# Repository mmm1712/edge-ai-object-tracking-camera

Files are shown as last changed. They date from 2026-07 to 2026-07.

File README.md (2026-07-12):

# Local Edge AI Object-Tracking Camera

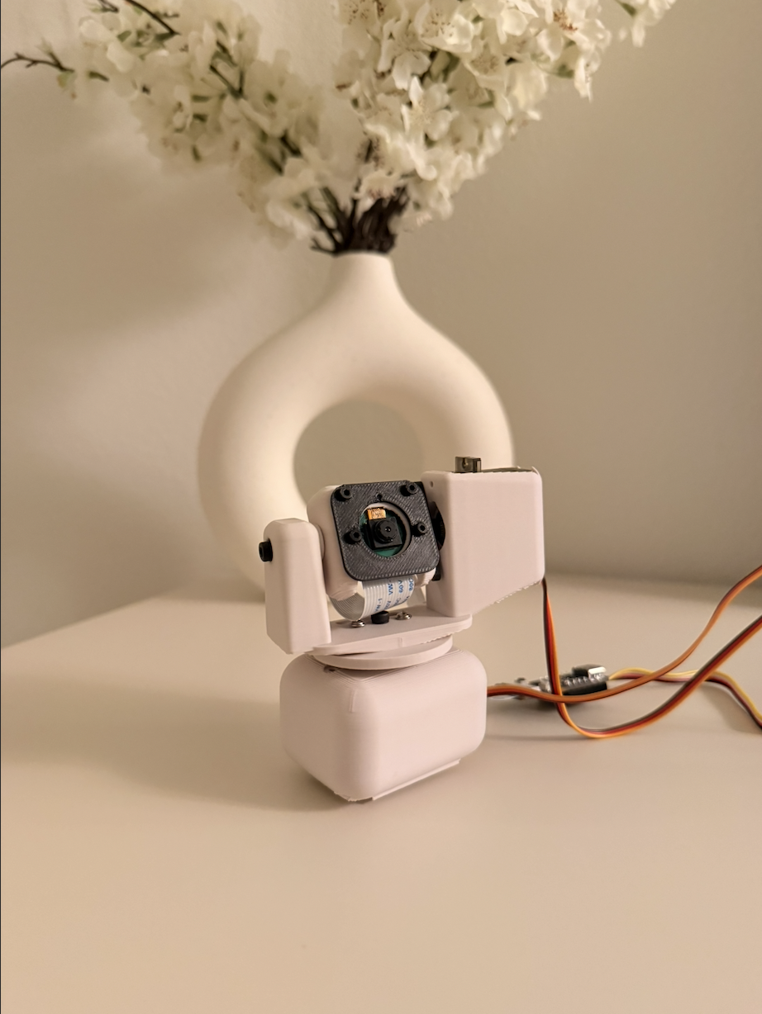
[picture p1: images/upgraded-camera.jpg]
Upgraded object-tracking camera


## Why I Rebuilt It

My first object-tracking camera used an ESP32-CAM to stream video to my laptop. A YOLO model running on the laptop detected the object, and the laptop sent movement commands to another ESP32 controlling the servos.

It worked, but the camera could not track anything without my laptop.

In this upgraded version, object detection runs locally on Grove Vision AI V2. The detected object position is sent to a XIAO ESP32-S3, which controls the pan and tilt servos.

I also redesigned the 3D-printed camera body to fit the new hardware.

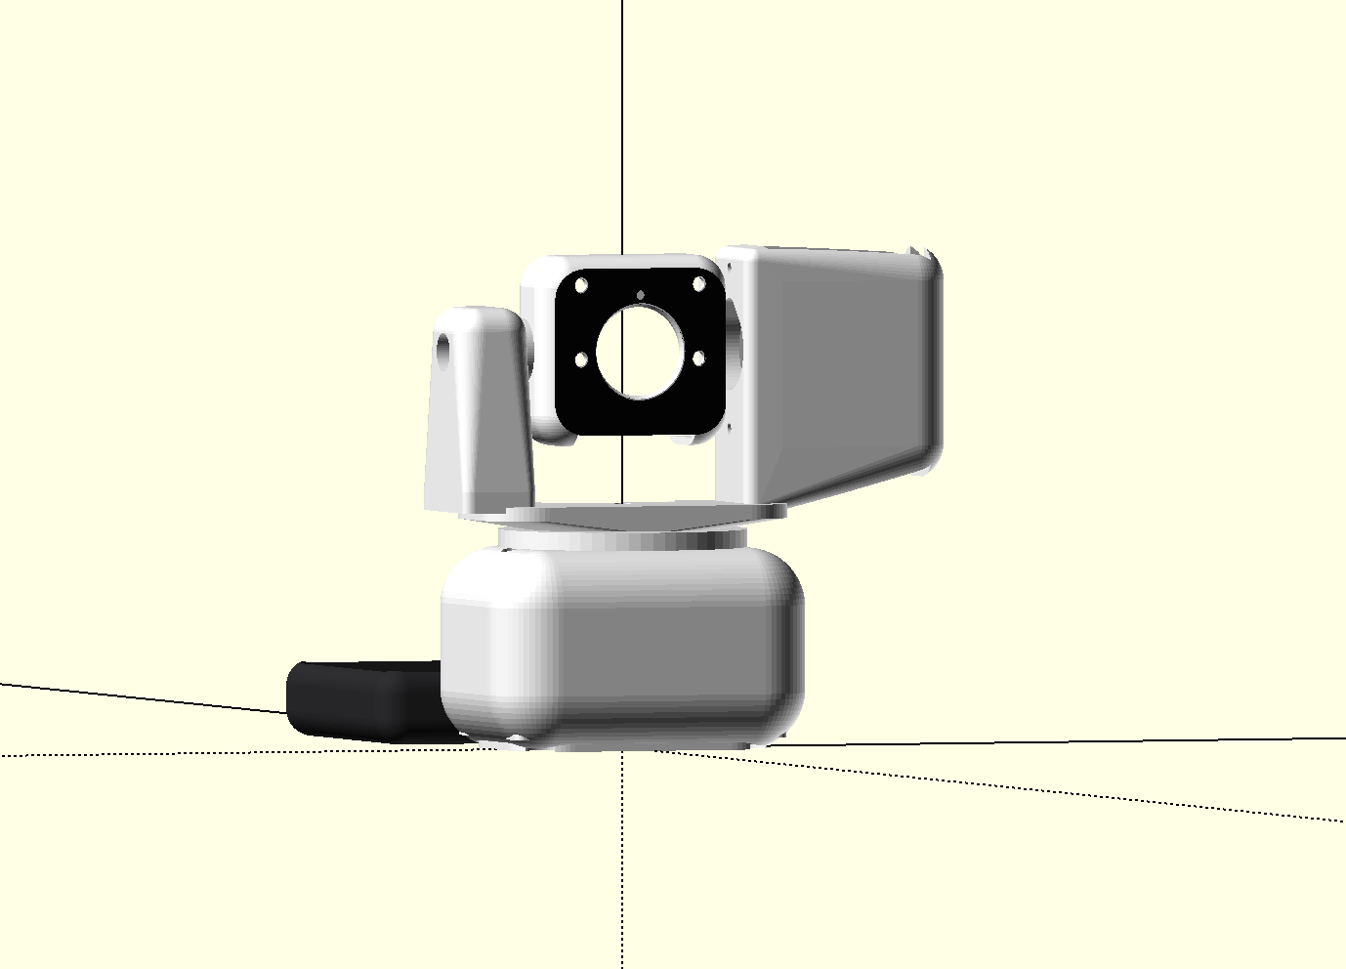
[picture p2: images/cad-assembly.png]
OpenSCAD assembly


## How It Works

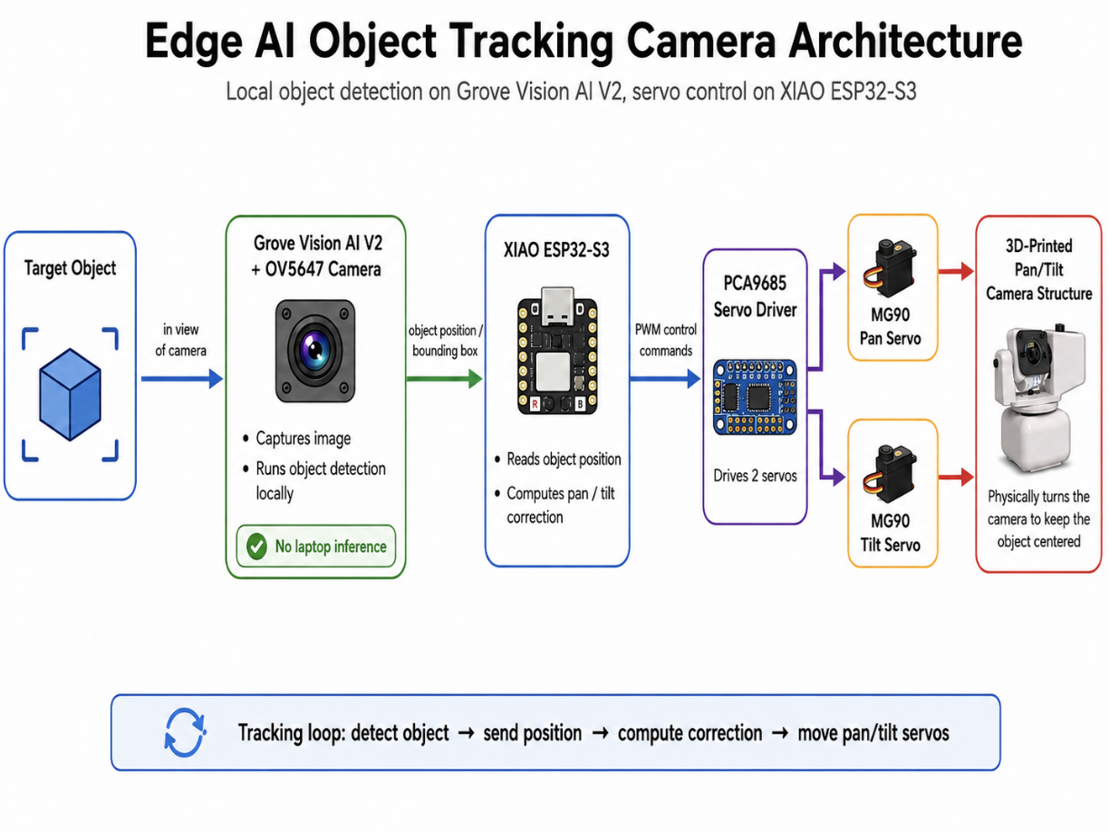
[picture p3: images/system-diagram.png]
Object-tracking system diagram


1. Grove Vision AI V2 detects the object.
2. It sends the object's position to the XIAO.
3. The XIAO compares that position with the center of the camera frame.
4. If the object is off-center, the XIAO moves the pan and tilt servos.
5. The camera turns toward the object.

Object detection and servo control now run locally on the device.

## Demo

Camera following an object

The upgraded prototype can now detect an object, decide where to move, and physically follow it without relying on a laptop.

## Hardware

- Grove Vision AI V2 Kit
- XIAO ESP32-S3
- OV5647-62 FOV camera module
- 2 × MG90S metal gear micro servos
- PCA9685 servo driver
- External 5 V servo power supply
- Custom 3D-printed pan/tilt structure
- Jumper wires and mounting hardware

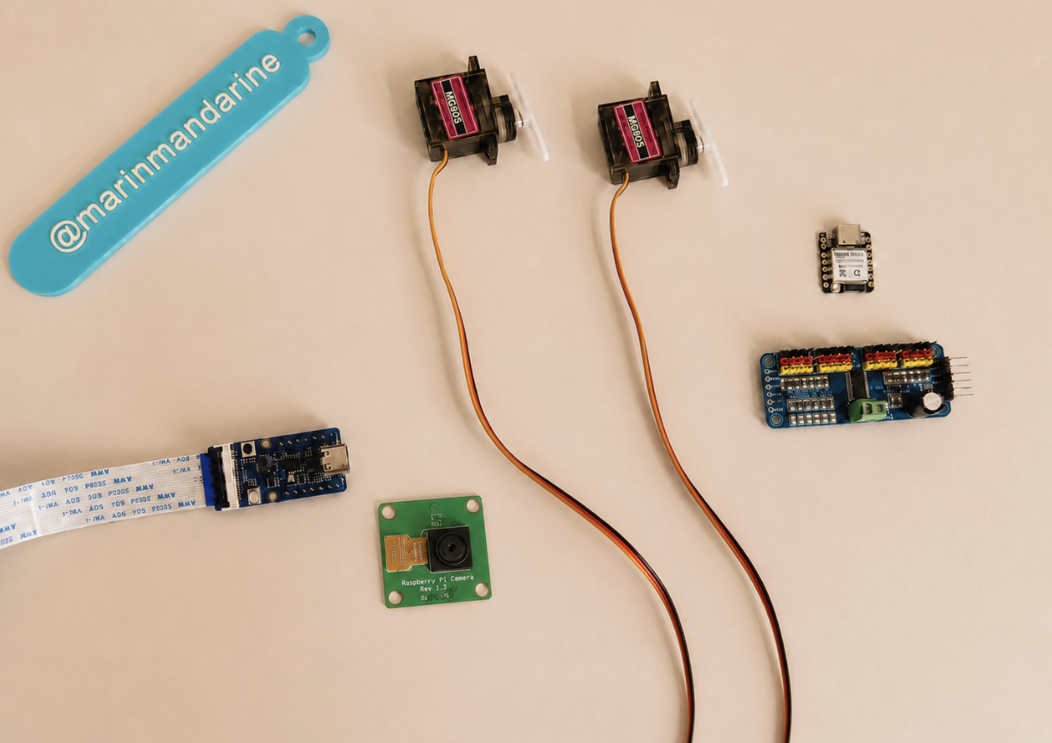
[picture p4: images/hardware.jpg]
Main hardware


## Servo Control

The XIAO checks how far the object is from the center of the frame:

```cpp
errorX = objectCenterX - frameCenterX;
errorY = objectCenterY - frameCenterY;
```

The error is converted into a target servo speed:

```cpp
panSpeed  = clamp(KpPan * errorX, -maxPanSpeed, maxPanSpeed);
tiltSpeed = clamp(KpTilt * errorY, -maxTiltSpeed, maxTiltSpeed);
```

If the object is far from the center, the camera moves faster. If it is only slightly off-center, it moves more slowly.

A dead zone prevents tiny movements when the object is already close to the center. Acceleration limits make the speed change gradually instead of jumping instantly.

Accurate detection alone is not enough. Smooth and stable servo control is also important for reliable tracking.

## Wiring

See [`docs/wiring.md`](docs/wiring.md).

The servos use an external 5 V power supply. The external power ground and XIAO ground must be connected together.

## Software

### Required Arduino Libraries

- Seeed Arduino SSCMA
- Adafruit PWM Servo Driver Library

### Uploading the Firmware

1. Install the required libraries in Arduino IDE.
2. Open:
   `firmware/grove_vision_ai_object_tracker/grove_vision_ai_object_tracker.ino`
3. Select the XIAO ESP32-S3 board and the correct port.
4. Upload the sketch.
5. Open Serial Monitor at `115200` baud.
6. A successful start should print:

```text
AI BEGIN OK
```

### Tracking Settings

The most important values are grouped near the beginning of the sketch:

- Servo center positions
- Mechanical movement limits
- Servo directions
- Proportional gains
- Maximum speed
- Acceleration
- Dead-zone sizes
- Detection smoothing

These values may need small adjustments for a different pan/tilt structure.

## Original Version vs. Upgraded Version

### Original Version

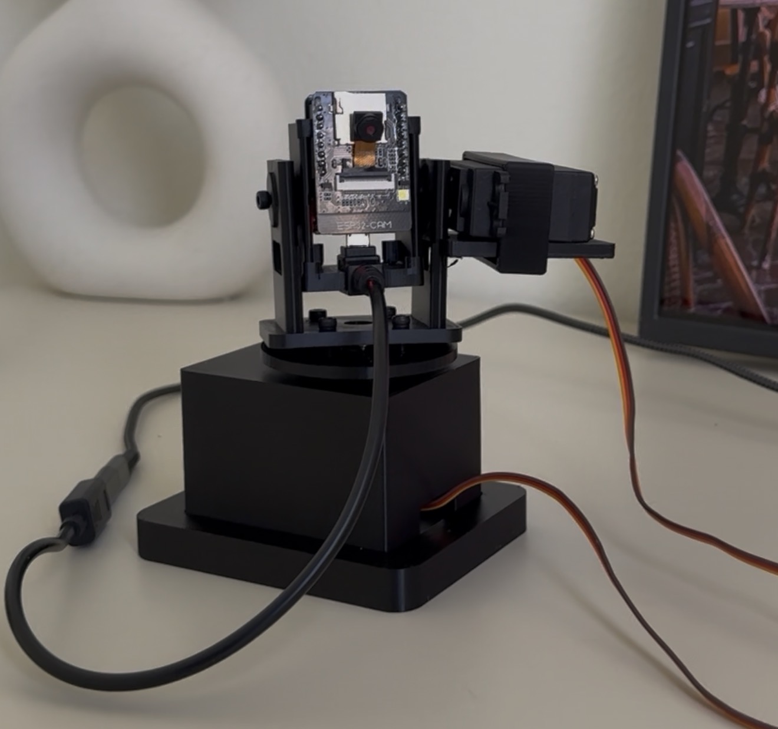
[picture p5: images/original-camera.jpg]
Original camera


The original version streamed video to my laptop, where a YOLO model detected the object.

### Upgraded Version

The upgraded version runs object detection locally on Grove Vision AI V2.

| Feature | Original Version | Upgraded Version |
| --- | --- | --- |
| Camera system | ESP32-CAM | Grove Vision AI V2 + OV5647 camera |
| AI inference | Laptop | Grove Vision AI V2 |
| Servo control | Second ESP32 | XIAO ESP32-S3 + PCA9685 |
| Servos | MG995/MG996-style servos | MG90S servos |
| Tracking loop | Laptop YOLO + serial commands | Local detection + servo control |
| Portability | Limited | More compact |
| Main limitation | Required laptop inference | Still needs a cleaner enclosure and power system |

The biggest upgrade is not only the hardware. It is the architecture. Moving object detection onto the embedded vision module brings the project much closer to a standalone edge AI camera.

## Project Structure

```text
edge-ai-object-tracking-camera/
├── firmware/
│   └── grove_vision_ai_object_tracker/
│       └── grove_vision_ai_object_tracker.ino
├── docs/
│   └── wiring.md
├── images/
│   ├── cad-assembly.png
│   ├── hardware.jpg
│   ├── original-camera.jpg
│   ├── system-diagram.png
│   ├── tracking-demo.gif
│   ├── upgraded-camera.jpg
│   └── README.md
├── cad/
│   ├── source/
│   │   └── object_tracking_camera.scad
│   ├── stl/
│   │   ├── base.stl
│   │   ├── base_cover.stl
│   │   ├── yoke.stl
│   │   ├── camera_head.stl
│   │   └── faceplate_insert.stl
│   └── README.md
├── .gitignore
├── LICENSE
└── README.md
```

## What I Want to Improve Next

- Cleaner wiring
- A better electronics enclosure
- Battery power and power management
- Smoother servo movement
- Better mechanical balance
- More latency and response-time testing
- A larger and more varied training dataset

One future idea is to turn this into a small nature or wildlife monitoring camera. That would require a stronger enclosure, reliable power, and environmental protection.

## Current Status

This is still a prototype, but the main local edge AI tracking loop is working.

The camera can now:

- Detect the object locally
- Send its position to the XIAO
- Move the pan and tilt servos
- Follow the object without a laptop

## License

This project is available under the MIT License.

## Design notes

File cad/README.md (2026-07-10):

# CAD Files

This folder contains the 3D-printable parts and the OpenSCAD source file for the custom pan/tilt camera structure.

## Folder Structure

```text
cad/
├── source/
│   └── object_tracking_camera.scad
├── stl/
│   ├── base.stl
│   ├── base_cover.stl
│   ├── yoke.stl
│   ├── camera_head.stl
│   └── faceplate_insert.stl
└── renders/

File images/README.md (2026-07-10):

# Project Images

This folder contains the main photos, diagrams, and demo files used in the project README.

## Files

- `tracking-demo.gif` - demo of the camera following the detected object
- `original-camera.jpg` — the first ESP32-CAM version that depended on a laptop
- `upgraded-camera.jpg` — the upgraded camera using Grove Vision AI V2 and XIAO ESP32-S3
- `hardware.jpg` — the main hardware used to build the upgraded version
- `system-diagram.png` — diagram showing how object detection and servo control work
- `cad-assembly.png` — OpenSCAD render of the custom pan/tilt camera structure

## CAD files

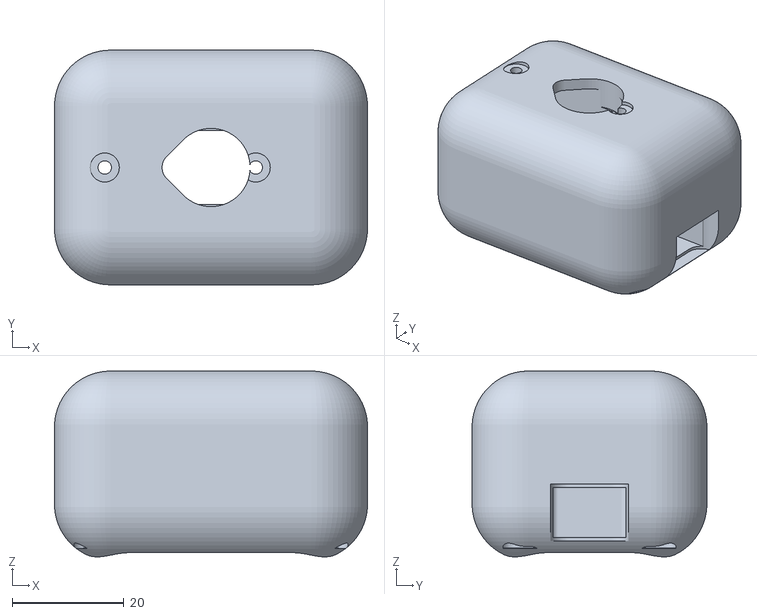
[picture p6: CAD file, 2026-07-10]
cad/stl/base.stl
56.0 x 42.0 x 33.2

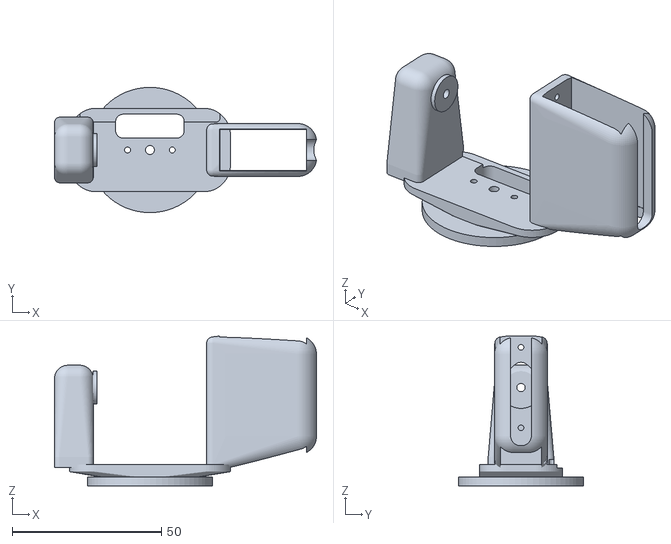
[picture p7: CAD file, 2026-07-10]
cad/stl/yoke.stl
87.9 x 42.0 x 50.3

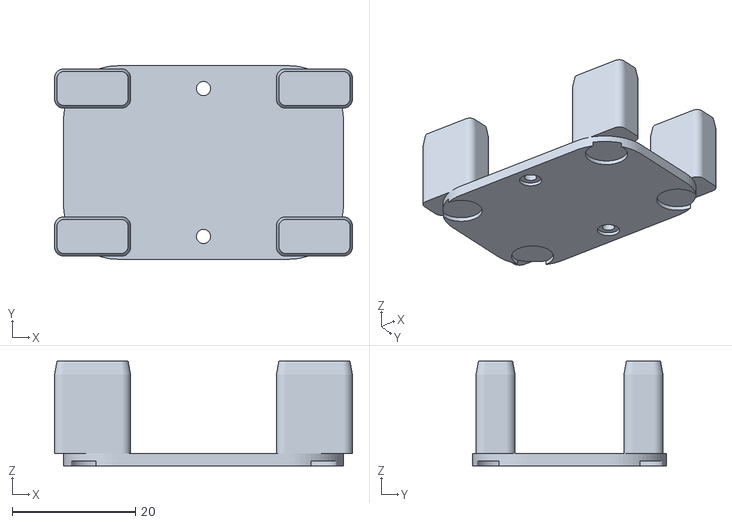
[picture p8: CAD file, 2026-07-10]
cad/stl/base_cover.stl
48.4 x 31.4 x 17.0

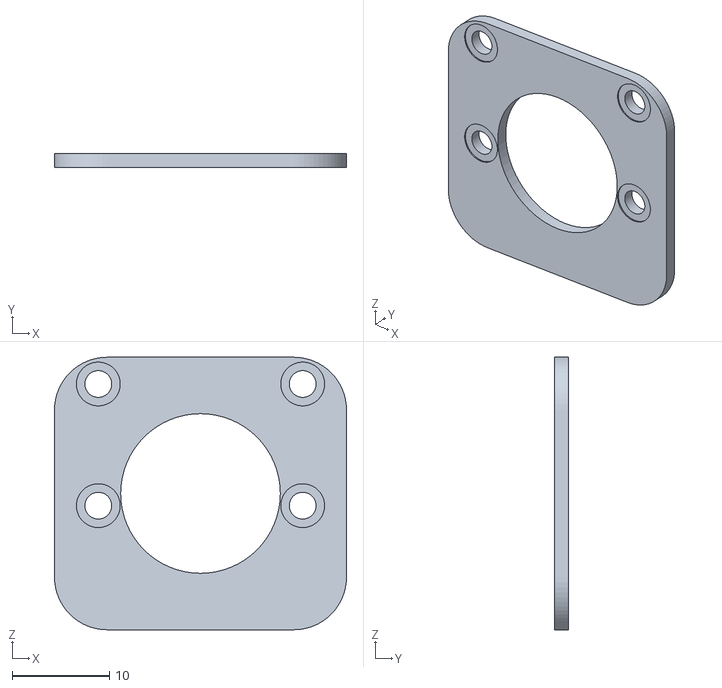
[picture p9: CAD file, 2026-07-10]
cad/stl/faceplate_insert.stl
30.0 x 1.40 x 28.0

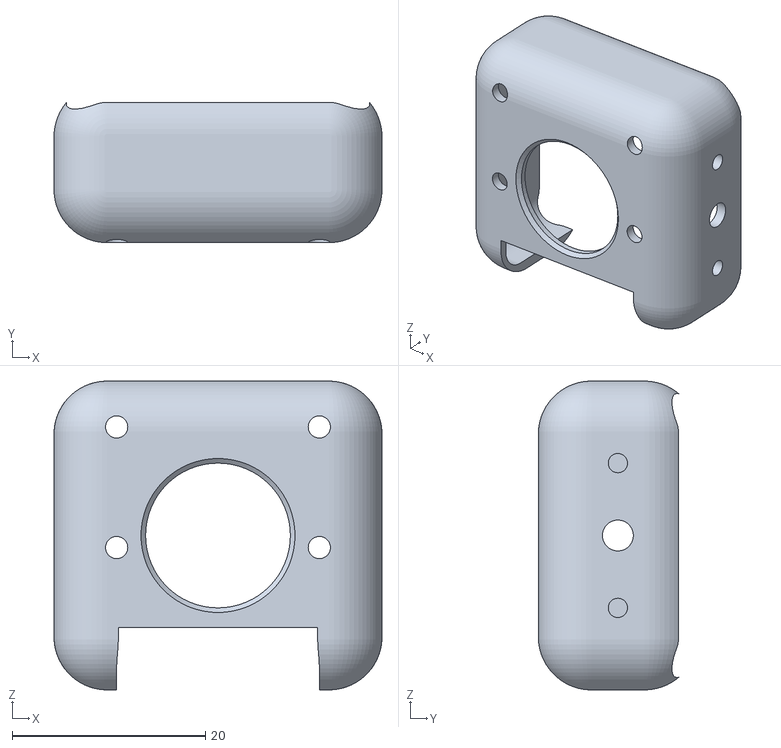
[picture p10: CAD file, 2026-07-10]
cad/stl/camera_head.stl
34.0 x 14.5 x 32.0

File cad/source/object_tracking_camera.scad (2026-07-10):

$fn = 64;
eps = 0.01;

show_part = "assembly";
/*
  Options:
  "assembly"
  "base"
  "base_cover"
  "yoke"
  "camera_head"
  "faceplate_insert"
*/

sv_body_w = 12.2;
sv_body_d = 28.5;
sv_tab_l = 32.5;
sv_screw_d = 2.4;
sv_screw_sp = 27.0;
sv_shaft_off = 5.5;
sv_boss_d = 14.0;
sv_boss_nose = 5.5;

cam_screw_sp_x = 21.0;
cam_screw_sp_z = 12.5;
cam_hole_z_off = 5.0;
cam_screw_d = 2.3;
lens_d = 15.0;
fpc_w = 21.0;

base_w = 56;
base_d = 42;
base_h = 33.8;
deck_t = 2.4;
yoke_axis_z = 33;
arm_in_x = 19;
head_w = 34;
head_d = 16.5;
head_h = 32;

side_pod_h = 40.0;
side_pod_y = 17.8;
side_pod_r = 6.4;
side_pod_zc = 30.5;

base_cover_tab_clear = 0.65;
base_cover_tab_h = 15.0;
base_cover_tab_lead_h = 2.2;
base_cover_tab_x = 13.0 - base_cover_tab_clear;
base_cover_tab_y = 7.0 - base_cover_tab_clear;
base_cover_tab_lead_x = base_cover_tab_x - 0.8;
base_cover_tab_lead_y = base_cover_tab_y - 0.8;

wall_t = 13;
module soft_box(size=[10,10,10], r=3) {
    x=size[0]; y=size[1]; z=size[2];
    hull()
    for (xx=[-x/2+r, x/2-r])
    for (yy=[-y/2+r, y/2-r])
    for (zz=[-z/2+r, z/2-r])
        translate([xx,yy,zz]) sphere(r=r);
}

module rounded_box(size=[10,10,10], r=2) {
    x=size[0]; y=size[1]; z=size[2];
    hull()
    for (xx=[-x/2+r, x/2-r])
    for (yy=[-y/2+r, y/2-r])
        translate([xx,yy,0]) cylinder(h=z, r=r, center=true);
}


module rounded_plate_xz(w=20, z=20, t=1.0, r=4) {
    hull()
    for (xx=[-w/2+r, w/2-r])
    for (zz=[-z/2+r, z/2-r])
        translate([xx, 0, zz])
            rotate([90,0,0]) cylinder(r=r, h=t, center=true);
}

module hole_x(d=3, h=20) { rotate([0,90,0]) cylinder(d=d, h=h, center=true); }

module hole_y(d=3, h=20) { rotate([90,0,0]) cylinder(d=d, h=h, center=true); }

module hole_z(d=3, h=20) { cylinder(d=d, h=h, center=true); }

module boss_clear_z(d=14, nose_d=5.5, nose_off=-5.5, h=12) {
    hull() {
        hole_z(d=d, h=h);
        translate([nose_off,0,0]) hole_z(d=nose_d, h=h);
    }
}

module base() {
    difference() {
        translate([0,0,base_h/2])
            soft_box([base_w, base_d, base_h], r=10);

        translate([-sv_shaft_off, 0, (base_h - deck_t)/2 - 0.1])
            rounded_box([sv_tab_l + 1.0, sv_body_w + 1.0, base_h - deck_t + 0.2], r=1.0);

        translate([0,0,base_h - deck_t/2])
            boss_clear_z(d=sv_boss_d, nose_d=sv_boss_nose, nose_off=-6.0, h=deck_t + 8);

        for (xx = [-sv_screw_sp/2, sv_screw_sp/2]) {
            translate([-sv_shaft_off + xx, 0, base_h/2])
                hole_z(d=sv_screw_d, h=base_h + 4);
            translate([-sv_shaft_off + xx, 0, base_h - 0.35])
                hole_z(d=5.2, h=0.8);
        }

        translate([0,0,0])
            rounded_box([46, 32, 4.4], r=9);

        for (yy = [-12, 12])
            translate([0, yy, 5])
                hole_z(d=1.7, h=10);

        for (xx = [-18, 18]) for (yy = [-12, 12])
            translate([xx, yy, 15.1])
                rounded_box([13, 7, 26], r=2);

        translate([base_w/4 + 3.0, 0, 8.5])
            rounded_box([base_w/2 + 12, 13.0, 9.0], r=2.7);

        translate([base_w/2 - 1.2, 0, 8.5])
            rounded_box([8.0, 14.0, 10.2], r=3.2);
    }
}

module base_cover_locator_tab() {

    hull() {
        translate([0,0,(base_cover_tab_h - base_cover_tab_lead_h)/2])
            rounded_box([base_cover_tab_x,
                         base_cover_tab_y,
                         base_cover_tab_h - base_cover_tab_lead_h], r=1.45);
        translate([0,0,base_cover_tab_h - base_cover_tab_lead_h/2])
            rounded_box([base_cover_tab_lead_x,
                         base_cover_tab_lead_y,
                         base_cover_tab_lead_h], r=1.2);
    }
}

module base_cover() {
    difference() {
        union() {

            translate([0,0,1.0])
                rounded_box([45.4, 31.4, 2.0], r=8.7);

            for (xx = [-18, 18]) for (yy = [-12, 12])
                translate([xx, yy, 2.0])
                    base_cover_locator_tab();
        }

        for (yy = [-12, 12]) {
            translate([0, yy, 1.0]) hole_z(d=2.3, h=6 + base_cover_tab_h);
            translate([0, yy, 0.3]) hole_z(d=4.2, h=0.7);
        }

        for (xx = [-17.5, 17.5]) for (yy = [-11, 11])
            translate([xx, yy, 0])
                hole_z(d=8, h=1.6);
    }
}

module left_minimal_arm(t=wall_t) {
    difference() {
        union() {
            hull() {

                translate([-arm_in_x - t/2, 0, 8.0])
                    rounded_box([t, 22.0, 3.6], r=1.8);

                translate([-arm_in_x - t/2, 0, yoke_axis_z])
                    soft_box([t, 17.5, 15], r=4.5);
            }

            translate([-arm_in_x + 0.6, 0, yoke_axis_z])
                rotate([0,90,0]) cylinder(d=11, h=1.4, center=true);
        }

        translate([-arm_in_x - t + 2.0, 0, yoke_axis_z])
            hole_x(d=6.5, h=4.6);

        translate([-arm_in_x - t/2 - 0.6, 0, yoke_axis_z])
            hole_x(d=3.4, h=t - 8.0);

        translate([-arm_in_x - 1.6, 0, yoke_axis_z])
            hole_x(d=2.8, h=6.6);
    }
}

module yoke() {
    axis = yoke_axis_z;
    plate_x0 = arm_in_x;
    plate_t  = 4.4;
    plate_x1 = plate_x0 + plate_t;
    body_x0  = plate_x1 + 0.25;
    cowl_x1  = body_x0 + sv_body_d + 2.2;
    difference() {
        union() {

            cylinder(d=42, h=3);

            hull() {
                translate([0,0,2.6]) cylinder(d=28, h=0.6);
                translate([0,0,5.4]) rounded_box([54, 28, 1.2], r=9);
            }

            translate([0,0,6.0]) rounded_box([54, 28, 2.4], r=9);

            difference() {
                hull() {
                    translate([(plate_x0+plate_x1)/2, 0, (axis + 17 + 5)/2])
                        soft_box([plate_t, 17.6, axis + 17 - 5], r=2.2);
                    translate([(plate_x0 + cowl_x1 + 1.6)/2, 0, side_pod_zc])
                        soft_box([cowl_x1 - plate_x0 + 1.6, side_pod_y, side_pod_h], r=side_pod_r);
                }

                translate([(plate_x1 + cowl_x1 - 2.0)/2 + 0.05, 0, 36.25])
                    cube([cowl_x1 - 2.0 - plate_x1 + 0.3, sv_body_w + 1.8, 42.0], center=true);

                translate([(body_x0 + cowl_x1 - 2.0)/2, 0, 10])
                    cube([cowl_x1 - 2.0 - body_x0 + 0.2, sv_body_w + 1.6, 13.5], center=true);

                translate([cowl_x1, 0, 36.0])
                    rotate([0,90,0])
                        rounded_box([45.0, 7.0, 10.0], r=3.4);
            }

            left_minimal_arm();
        }

        translate([0,0,1.3 - eps]) {
            cylinder(d=9.2, h=2.7, center=true);
            rounded_box([36.5, 7.4, 2.7], r=2);
        }

        hole_z(d=3.0, h=18);
        for (xx = [-7.5, 7.5])
            translate([xx,0,0]) hole_z(d=2.0, h=16);

        translate([0, 8.0, 4]) rounded_box([23, 8.0, 12], r=2.5);

        translate([0, 12.3, 7.4]) rounded_box([47, 5.8, 2.8], r=1.2);

        translate([(plate_x0+plate_x1)/2, 0, axis])
            hull() {
                hole_x(d=sv_boss_d, h=plate_t + 10);
                translate([0,0,5.5]) hole_x(d=6.0, h=plate_t + 10);
            }

        for (zz = [-sv_screw_sp/2, sv_screw_sp/2])
            translate([(plate_x0+plate_x1)/2, 0, axis + zz])
                hole_x(d=1.9, h=plate_t + 8);

        for (xx = [26, 30])
            translate([xx, 7.5, 11])
                rounded_box([1.8, 6, 7], r=0.8);
    }
}

module camera_head() {
    difference() {

        soft_box([head_w, head_d, head_h], r=5.5);

        translate([0, 1.3, 0])
            soft_box([head_w - 2.6, head_d + 0.2, head_h - 2.6], r=3.0);

        translate([0, 5.6, 0])
            rounded_box([27.5, 12.0, 26.5], r=4);

        translate([0, -head_d/2, 0]) hole_y(d=lens_d, h=head_d + 6);
        translate([0, -head_d/2 - 0.4, 0])
            rotate([90,0,0])
                cylinder(d1=lens_d, d2=lens_d + 3.5, h=1.8, center=true);

        for (x = [-cam_screw_sp_x/2, cam_screw_sp_x/2])
        for (z = [-cam_screw_sp_z/2, cam_screw_sp_z/2])
            translate([x, -head_d/2 + 0.7, z + cam_hole_z_off])
                hole_y(d=cam_screw_d, h=4);

        translate([0, 1, -head_h/2 + 3.2])
            rounded_box([fpc_w, head_d + 6, 6.5], r=3);
        translate([0, head_d/2 - 1, -9])
            rotate([0,90,0])
                rounded_box([13, 8, fpc_w], r=4);

        translate([-head_w/2, 0, 0]) hole_x(d=4.2, h=12);

        translate([head_w/2, 0, 0]) {
            hole_x(d=3.2, h=12);
            for (zz = [-7.5, 7.5])
                translate([0, 0, zz]) hole_x(d=2.0, h=12);
        }
    }
}


module camera_faceplate_insert() {
    fp_y = -head_d/2 - 0.68;
    fp_t = 1.4;
    fp_w = head_w - 4.0;
    fp_z = head_h - 4.0;
    fp_r = 5.4;
    faceplate_screw_access_d = cam_screw_d + 0.45;
    faceplate_screw_bezel_d = 4.5;

    difference() {
        translate([0, fp_y, 0])
            rounded_plate_xz(w=fp_w, z=fp_z, t=fp_t, r=fp_r);

        translate([0, fp_y, 0])
            hole_y(d=lens_d + 1.4, h=fp_t + 3);
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

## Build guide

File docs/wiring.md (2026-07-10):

# Wiring

The project uses two separate I2C buses on the XIAO ESP32-S3.

## Grove Vision AI V2

| Signal | XIAO ESP32-S3 |
| --- | --- |
| SDA | GPIO 5 |
| SCL | GPIO 6 |
| GND | GND |
| Power | Connect according to the module requirements |

## PCA9685 Servo Driver

| Signal | XIAO ESP32-S3 |
| --- | --- |
| SDA | GPIO 9 |
| SCL | GPIO 7 |
| GND | GND |
| Logic power | Connect according to the PCA9685 board requirements |

## Servos

| Servo | PCA9685 Channel |
| --- | --- |
| Pan | 0 |
| Tilt | 1 |

The servos are powered from an external 5 V supply.

**Important:** Connect the external power supply ground to the XIAO ground so all parts of the system share the same reference.

Do not power both servos from the XIAO 3.3 V pin.

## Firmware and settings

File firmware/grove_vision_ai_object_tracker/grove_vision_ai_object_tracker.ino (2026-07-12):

/*
  Local Edge AI Object-Tracking Camera

  Hardware:
  - Grove Vision AI V2
  - Seeed Studio XIAO ESP32-S3
  - PCA9685 servo driver
  - 2 x MG90S servos
  - External 5 V servo power supply

  Libraries:
  - Seeed Arduino SSCMA
  - Adafruit PWM Servo Driver Library

  Wiring used in this project:
  Grove Vision AI V2:
    SDA -> XIAO D4 / GPIO 5
    SCL -> XIAO D5 / GPIO 6

  PCA9685:
    SDA -> XIAO GPIO 9
    SCL -> XIAO GPIO 7

  Important:
  Power the servos from an external 5 V supply and connect
  the external supply ground to the XIAO ground.
*/

#include <Arduino.h>
#include <Wire.h>
#include <Adafruit_PWMServoDriver.h>
#include <Seeed_Arduino_SSCMA.h>

#define AI_SDA 5
#define AI_SCL 6
#define PCA_SDA 9
#define PCA_SCL 7
#define PCA9685_ADDR 0x40

TwoWire AIWire = TwoWire(0);
TwoWire ServoWire = TwoWire(1);

SSCMA AI;
Adafruit_PWMServoDriver pwm(PCA9685_ADDR, ServoWire);

constexpr float FRAME_WIDTH = 240.0f;
constexpr float FRAME_HEIGHT = 240.0f;
constexpr float FRAME_CENTER_X = FRAME_WIDTH / 2.0f;
constexpr float FRAME_CENTER_Y = FRAME_HEIGHT / 2.0f;

constexpr int PAN_CHANNEL = 0;
constexpr int TILT_CHANNEL = 1;
constexpr int SERVO_MIN_PULSE = 110;
constexpr int SERVO_MAX_PULSE = 500;
constexpr int SERVO_TICK_MS = 20;

constexpr int MIN_DETECTION_SCORE = 50;

constexpr unsigned long TARGET_STALE_MS = 550;

constexpr float FILTER_ALPHA_X = 0.62f;

constexpr float FILTER_ALPHA_Y = 0.30f;
constexpr float BASE_MAX_Y_JUMP_PX = 30.0f;
constexpr float BOX_HEIGHT_JUMP_SCALE = 0.45f;
constexpr int STRONG_Y_JUMP_SCORE = 82;
constexpr int Y_JUMP_CONFIRM_FRAMES = 2;
constexpr float Y_JUMP_CONFIRM_TOLERANCE_PX = 16.0f;

constexpr float Y_LOCK_PAN_ERROR_PX = 22.0f;
constexpr float Y_LOCK_MAX_Y_ERROR_PX = 18.0f;
constexpr float TILT_AIM_OFFSET_Y_PX = 0.0f;

constexpr uint16_t AI_I2C_ADDRESS = 0x62;
constexpr uint32_t AI_I2C_WAIT_MS = 1;
constexpr uint32_t AI_I2C_CLOCK_HZ = 400000;

constexpr int INVOKE_FAILURE_BACKOFF_MS = 20;

struct AxisController {
  int channel;
  float minAngle;
  float centerAngle;
  float maxAngle;
  int direction;
  float deadzonePx;
  float kp;
  float maxVelocityDps;
  float minVelocityDps;
  float accelerationDps2;
  float currentAngle;
  float currentVelocityDps;
  int lastPulse;
};

struct TargetTracker {
  float filteredX;
  float filteredY;

  float errorX;
  float errorY;

  float pendingY;
  int pendingYFrames;

  int lastRawY;
  int lastScore;
  bool lastYRejected;

  bool filterReady;
  bool targetVisible;
  unsigned long lastSeenMs;
};

AxisController panAxis = {
  PAN_CHANNEL,
  35.0f,
  90.0f,
  145.0f,
  -1,
  8.0f,
  1.65f,
  145.0f,
  3.5f,
  700.0f,
  90.0f,
  0.0f,
  -1
};

AxisController tiltAxis = {
  TILT_CHANNEL,
  95.0f,
  125.0f,
  140.0f,
  -1,
  14.0f,    
  1.85f,   
  125.0f,   
  4.0f,
  650.0f,  
  125.0f,
  0.0f,
  -1
};

TargetTracker tracker = {
  FRAME_CENTER_X,
  FRAME_CENTER_Y,
  0.0f,
  0.0f,
  FRAME_CENTER_Y,
  0,
  0,
  0,
  false,
  false,
  false,
  0
};

SemaphoreHandle_t stateMutex;

bool aiOK = false;
bool trackingEnabled = false;

portMUX_TYPE statsMux = portMUX_INITIALIZER_UNLOCKED;

uint32_t totalInvokeOK = 0;
uint32_t totalInvokeFail = 0;

uint32_t windowInvokeOK = 0;
uint32_t windowInvokeFail = 0;
uint32_t windowDetectionFrames = 0;

uint64_t windowInvokeTimeUs = 0;
uint32_t lastInvokeUs = 0;

int lastPreprocessMs = 0;
int lastInferenceMs = 0;
int lastPostprocessMs = 0;

unsigned long lastTimingPrintMs = 0;

float clampFloat(float value, float minimum, float maximum) {
  if (value < minimum) return minimum;
  if (value > maximum) return maximum;
  return value;
}

float absFloat(float value) {
  return value < 0.0f ? -value : value;
}

float signFloat(float value) {
  if (value > 0.0f) return 1.0f;
  if (value < 0.0f) return -1.0f;
  return 0.0f;
}

float moveToward(float current, float target, float maxChange) {
  float difference = target - current;
  if (absFloat(difference) <= maxChange) return target;
  return current + signFloat(difference) * maxChange;
}

float easeOutCubic(float value) {
  value = clampFloat(value, 0.0f, 1.0f);
  float remaining = 1.0f - value;
  return 1.0f - remaining * remaining * remaining;
}

int angleToPulse(float angle) {
  angle = clampFloat(angle, 0.0f, 180.0f);
  float normalized = angle / 180.0f;
  return static_cast<int>(
    SERVO_MIN_PULSE +
    normalized * (SERVO_MAX_PULSE - SERVO_MIN_PULSE) +
    0.5f
  );
}

void writeAxis(AxisController &axis) {
  axis.currentAngle = clampFloat(
    axis.currentAngle,
    axis.minAngle,
    axis.maxAngle
  );

  int pulse = angleToPulse(axis.currentAngle);
  if (pulse == axis.lastPulse) return;

  axis.lastPulse = pulse;
  pwm.setPWM(axis.channel, 0, pulse);
}

void writeServos() {
  writeAxis(panAxis);
  writeAxis(tiltAxis);
}

float calculateTargetVelocity(float error, const AxisController &axis) {
  float magnitude = absFloat(error);
  if (magnitude <= axis.deadzonePx) return 0.0f;

  float effectiveError = magnitude - axis.deadzonePx;
  float velocity = axis.kp * effectiveError;

  if (velocity > 0.0f && velocity < axis.minVelocityDps) {
    velocity = axis.minVelocityDps;
  }

  velocity = clampFloat(velocity, 0.0f, axis.maxVelocityDps);
  return signFloat(error) * velocity;
}

void resetTrackingNoLock() {
  tracker.filteredX = FRAME_CENTER_X;
  tracker.filteredY = FRAME_CENTER_Y + TILT_AIM_OFFSET_Y_PX;
  tracker.errorX = 0.0f;
  tracker.errorY = 0.0f;

  tracker.pendingY = FRAME_CENTER_Y;
  tracker.pendingYFrames = 0;
  tracker.lastRawY = 0;
  tracker.lastScore = 0;
  tracker.lastYRejected = false;

  tracker.filterReady = false;
  tracker.targetVisible = false;
  tracker.lastSeenMs = 0;
  panAxis.currentVelocityDps = 0.0f;
  tiltAxis.currentVelocityDps = 0.0f;
}

void centerSmooth() {
  float startPan = panAxis.currentAngle;
  float startTilt = tiltAxis.currentAngle;

  if (xSemaphoreTake(stateMutex, pdMS_TO_TICKS(20)) == pdTRUE) {
    resetTrackingNoLock();
    xSemaphoreGive(stateMutex);
  }

  constexpr int durationMs = 800;
  constexpr int intervalMs = 20;
  constexpr int steps = durationMs / intervalMs;

  panAxis.lastPulse = -1;
  tiltAxis.lastPulse = -1;

  for (int step = 1; step <= steps; step++) {
    float progress = static_cast<float>(step) / static_cast<float>(steps);
    float eased = easeOutCubic(progress);

    panAxis.currentAngle =
      startPan + (panAxis.centerAngle - startPan) * eased;

    tiltAxis.currentAngle =
      startTilt + (tiltAxis.centerAngle - startTilt) * eased;

    writeServos();
    delay(intervalMs);
  }

  panAxis.currentAngle = panAxis.centerAngle;
  tiltAxis.currentAngle = tiltAxis.centerAngle;
  panAxis.currentVelocityDps = 0.0f;
  tiltAxis.currentVelocityDps = 0.0f;
  writeServos();
}

bool beginAI() {
  bool success = AI.begin(
    &AIWire,
    -1,
    AI_I2C_ADDRESS,
    AI_I2C_WAIT_MS,
    AI_I2C_CLOCK_HZ
  );

  Serial.println(success ? "AI BEGIN OK" : "AI BEGIN FAIL");
  return success;
}

bool readBestBox(
  int &x,
  int &y,
  int &width,
  int &height,
  int &score,
  int &target
) {
  int count = AI.boxes().size();
  if (count == 0) return false;

  int bestIndex = -1;
  long bestValue = -1;

  for (int index = 0; index < count; index++) {
    int currentScore = AI.boxes()[index].score;
    if (currentScore < MIN_DETECTION_SCORE) continue;

    int boxWidth = AI.boxes()[index].w;
    int boxHeight = AI.boxes()[index].h;
    long area = static_cast<long>(boxWidth) * boxHeight;
    long value = static_cast<long>(currentScore) * 1000L + area;

    if (value > bestValue) {
      bestValue = value;
      bestIndex = index;
    }
  }

  if (bestIndex < 0) return false;

  auto box = AI.boxes()[bestIndex];
  x = box.x;
  y = box.y;
  width = box.w;
  height = box.h;
  score = box.score;
  target = box.target;
  return true;
}

void updateTarget(
  int detectedX,
  int detectedY,
  int boxWidth,
  int boxHeight,
  int score
) {
  if (xSemaphoreTake(stateMutex, pdMS_TO_TICKS(20)) != pdTRUE) return;

  tracker.lastSeenMs = millis();
  tracker.targetVisible = true;
  tracker.lastRawY = detectedY;
  tracker.lastScore = score;
  tracker.lastYRejected = false;

  if (!tracker.filterReady) {
    tracker.filteredX = detectedX;
    tracker.filteredY = detectedY;
    tracker.pendingY = detectedY;
    tracker.pendingYFrames = 0;
    tracker.filterReady = true;
  } else {
    tracker.filteredX =
      tracker.filteredX * (1.0f - FILTER_ALPHA_X) +
      detectedX * FILTER_ALPHA_X;

    float yJump =
      absFloat(detectedY - tracker.filteredY);

    float adaptiveJumpLimit =
      boxHeight * BOX_HEIGHT_JUMP_SCALE;

    if (adaptiveJumpLimit < BASE_MAX_Y_JUMP_PX) {
      adaptiveJumpLimit = BASE_MAX_Y_JUMP_PX;
    }

    bool acceptY =
      yJump <= adaptiveJumpLimit ||
      score >= STRONG_Y_JUMP_SCORE;

    if (!acceptY) {
      // A single detector glitch is ignored. A real large movement normally
      // appears in two consecutive detections near the same new Y position.
      if (
        tracker.pendingYFrames > 0 &&
        absFloat(detectedY - tracker.pendingY) <=
          Y_JUMP_CONFIRM_TOLERANCE_PX
      ) {
        tracker.pendingYFrames++;
      } else {
        tracker.pendingY = detectedY;
        tracker.pendingYFrames = 1;
      }

      if (tracker.pendingYFrames >= Y_JUMP_CONFIRM_FRAMES) {
        acceptY = true;
      } else {
        tracker.lastYRejected = true;
      }
    }

    if (acceptY) {
      tracker.filteredY =
        tracker.filteredY * (1.0f - FILTER_ALPHA_Y) +
        detectedY * FILTER_ALPHA_Y;

      tracker.pendingY = detectedY;
      tracker.pendingYFrames = 0;
    }
  }

  float aimY = FRAME_CENTER_Y + TILT_AIM_OFFSET_Y_PX;
  float errorX = tracker.filteredX - FRAME_CENTER_X;
  float errorY = tracker.filteredY - aimY;

  if (absFloat(errorX) <= panAxis.deadzonePx) errorX = 0.0f;
  if (absFloat(errorY) <= tiltAxis.deadzonePx) errorY = 0.0f;

  // Ignore tiny vertical box movement while the target is mainly travelling
  // horizontally.
  if (
    absFloat(errorX) > Y_LOCK_PAN_ERROR_PX &&
    absFloat(errorY) < Y_LOCK_MAX_Y_ERROR_PX
  ) {
    errorY = 0.0f;
  }

  tracker.errorX = errorX;
  tracker.errorY = errorY;

  xSemaphoreGive(stateMutex);
}

void markNoFreshTarget() {
  if (xSemaphoreTake(stateMutex, pdMS_TO_TICKS(3)) != pdTRUE) return;

  if (millis() - tracker.lastSeenMs > TARGET_STALE_MS) {
    tracker.errorX = 0.0f;
    tracker.errorY = 0.0f;
    tracker.targetVisible = false;
    tracker.filterReady = false;
    tracker.pendingYFrames = 0;
    tracker.lastYRejected = false;
    panAxis.currentVelocityDps = 0.0f;
    tiltAxis.currentVelocityDps = 0.0f;
  }

  xSemaphoreGive(stateMutex);
}

void aiTask(void *parameter) {
  while (true) {
    if (!trackingEnabled || !aiOK) {
      vTaskDelay(pdMS_TO_TICKS(20));
      continue;
    }

    uint32_t invokeStartUs = micros();
    int result = AI.invoke(1, false, false);
    uint32_t invokeElapsedUs = micros() - invokeStartUs;

    int x = 0;
    int y = 0;
    int width = 0;
    int height = 0;
    int score = 0;
    int target = -1;

    bool hasBox = false;
    int preprocessMs = 0;
    int inferenceMs = 0;
    int postprocessMs = 0;

    if (result == 0) {
      hasBox = readBestBox(
        x,
        y,
        width,
        height,
        score,
        target
      );

      preprocessMs = AI.perf().prepocess;
      inferenceMs = AI.perf().inference;
      postprocessMs = AI.perf().postprocess;
    }

    portENTER_CRITICAL(&statsMux);

    lastInvokeUs = invokeElapsedUs;

    if (result == 0) {
      totalInvokeOK++;
      windowInvokeOK++;
      windowInvokeTimeUs += invokeElapsedUs;

      lastPreprocessMs = preprocessMs;
      lastInferenceMs = inferenceMs;
      lastPostprocessMs = postprocessMs;

      if (hasBox) {
        windowDetectionFrames++;
      }
    } else {
      totalInvokeFail++;
      windowInvokeFail++;
    }

    portEXIT_CRITICAL(&statsMux);

    if (result != 0) {
      markNoFreshTarget();

      vTaskDelay(pdMS_TO_TICKS(INVOKE_FAILURE_BACKOFF_MS));
      continue;
    }

    if (!hasBox) {
      markNoFreshTarget();
      taskYIELD();
      continue;
    }

    updateTarget(
      x,
      y,
      width,
      height,
      score
    );
    taskYIELD();
  }
}

void updateAxis(AxisController &axis, float error, float deltaTime) {
  float targetVelocity = calculateTargetVelocity(error, axis);
  float maxVelocityChange = axis.accelerationDps2 * deltaTime;

  axis.currentVelocityDps = moveToward(
    axis.currentVelocityDps,
    targetVelocity,
    maxVelocityChange
  );

  axis.currentAngle +=
    axis.direction * axis.currentVelocityDps * deltaTime;

  if (axis.currentAngle <= axis.minAngle) {
    axis.currentAngle = axis.minAngle;
    axis.currentVelocityDps = 0.0f;
  }

  if (axis.currentAngle >= axis.maxAngle) {
    axis.currentAngle = axis.maxAngle;
    axis.currentVelocityDps = 0.0f;
  }
}

void servoTask(void *parameter) {
  TickType_t lastWakeTime = xTaskGetTickCount();
  constexpr float deltaTime = SERVO_TICK_MS / 1000.0f;

  while (true) {
    float errorX = 0.0f;
    float errorY = 0.0f;
    unsigned long lastSeenMs = 0;

    if (xSemaphoreTake(stateMutex, pdMS_TO_TICKS(2)) == pdTRUE) {
      errorX = tracker.errorX;
      errorY = tracker.errorY;
      lastSeenMs = tracker.lastSeenMs;
      xSemaphoreGive(stateMutex);
    }

    bool targetStale = millis() - lastSeenMs > TARGET_STALE_MS;

    if (!trackingEnabled || targetStale) {
      errorX = 0.0f;
      errorY = 0.0f;
    }

    if (xSemaphoreTake(stateMutex, pdMS_TO_TICKS(2)) == pdTRUE) {
      updateAxis(panAxis, errorX, deltaTime);
      updateAxis(tiltAxis, errorY, deltaTime);
      xSemaphoreGive(stateMutex);
    }

    writeServos();

    vTaskDelayUntil(
      &lastWakeTime,
      pdMS_TO_TICKS(SERVO_TICK_MS)
    );
  }
}

void printTimingOncePerSecond() {
  unsigned long now = millis();
  unsigned long elapsedMs = now - lastTimingPrintMs;

  if (elapsedMs < 1000) return;
  lastTimingPrintMs = now;

  uint32_t okFrames;
  uint32_t failedFrames;
  uint32_t detectionFrames;
  uint64_t invokeTimeUs;
  uint32_t latestInvokeUs;
  uint32_t totalOK;
  uint32_t totalFail;

  int preprocessMs;
  int inferenceMs;
  int postprocessMs;

  portENTER_CRITICAL(&statsMux);

  okFrames = windowInvokeOK;
  failedFrames = windowInvokeFail;
  detectionFrames = windowDetectionFrames;
  invokeTimeUs = windowInvokeTimeUs;
  latestInvokeUs = lastInvokeUs;

  totalOK = totalInvokeOK;
  totalFail = totalInvokeFail;

  preprocessMs = lastPreprocessMs;
  inferenceMs = lastInferenceMs;
  postprocessMs = lastPostprocessMs;

  windowInvokeOK = 0;
  windowInvokeFail = 0;
  windowDetectionFrames = 0;
  windowInvokeTimeUs = 0;

  portEXIT_CRITICAL(&statsMux);

  float actualFps =
    elapsedMs > 0
      ? okFrames * 1000.0f / elapsedMs
      : 0.0f;

  float attemptFps =
    elapsedMs > 0
      ? (okFrames + failedFrames) * 1000.0f / elapsedMs
      : 0.0f;

  float detectionFps =
    elapsedMs > 0
      ? detectionFrames * 1000.0f / elapsedMs
      : 0.0f;

  float averageInvokeMs =
    okFrames > 0
      ? (invokeTimeUs / 1000.0f) / okFrames
      : 0.0f;

  int modelPipelineMs =
    preprocessMs + inferenceMs + postprocessMs;

  float modelPipelineFps =
    modelPipelineMs > 0
      ? 1000.0f / modelPipelineMs
      : 0.0f;

  bool visible = false;
  bool yRejected = false;
  int rawY = 0;
  int score = 0;
  float filteredY = 0.0f;
  float tiltError = 0.0f;
  float panAngle = 0.0f;
  float tiltAngle = 0.0f;

  if (xSemaphoreTake(stateMutex, pdMS_TO_TICKS(3)) == pdTRUE) {
    visible = tracker.targetVisible;
    yRejected = tracker.lastYRejected;
    rawY = tracker.lastRawY;
    score = tracker.lastScore;
    filteredY = tracker.filteredY;
    tiltError = tracker.errorY;
    panAngle = panAxis.currentAngle;
    tiltAngle = tiltAxis.currentAngle;
    xSemaphoreGive(stateMutex);
  }

  Serial.print("FPS=");
  Serial.print(actualFps, 2);

  Serial.print(" detectionFPS=");
  Serial.print(detectionFps, 2);

  Serial.print(" attempts=");
  Serial.print(attemptFps, 2);

  Serial.print(" avgInvokeMs=");
  Serial.print(averageInvokeMs, 1);

  Serial.print(" lastInvokeMs=");
  Serial.print(latestInvokeUs / 1000.0f, 1);

  Serial.print(" perf[");
  Serial.print(preprocessMs);
  Serial.print("+");
  Serial.print(inferenceMs);
  Serial.print("+");
  Serial.print(postprocessMs);
  Serial.print("ms]");

  Serial.print(" modelFPS=");
  Serial.print(modelPipelineFps, 2);

  Serial.print(" target=");
  Serial.print(visible ? "YES" : "NO");

  Serial.print(" y=");
  Serial.print(rawY);
  Serial.print("/");
  Serial.print(filteredY, 1);

  Serial.print(" yErr=");
  Serial.print(tiltError, 1);

  Serial.print(" yReject=");
  Serial.print(yRejected ? "YES" : "NO");

  Serial.print(" score=");
  Serial.print(score);

  Serial.print(" servo=");
  Serial.print(panAngle, 1);
  Serial.print(",");
  Serial.print(tiltAngle, 1);

  Serial.print(" ok=");
  Serial.print(totalOK);

  Serial.print(" fail=");
  Serial.println(totalFail);
}

void setup() {
  Serial.begin(115200);
  delay(1200);

  Serial.println();
  Serial.println("BOOT: Local Edge AI Object Tracker");

  stateMutex = xSemaphoreCreateMutex();

  if (stateMutex == nullptr) {
    Serial.println("ERROR: Could not create mutex");
    while (true) delay(1000);
  }

  AIWire.begin(AI_SDA, AI_SCL);
  AIWire.setClock(400000);

  ServoWire.begin(PCA_SDA, PCA_SCL);
  ServoWire.setClock(400000);

  pwm.begin();
  pwm.setPWMFreq(50);
  delay(200);

  centerSmooth();

  aiOK = beginAI();
  trackingEnabled = aiOK;
  lastTimingPrintMs = millis();

  xTaskCreatePinnedToCore(
    servoTask,
    "ServoTask",
    4096,
    nullptr,
    3,
    nullptr,
    1
  );

  xTaskCreatePinnedToCore(
    aiTask,
    "AITask",
    8192,
    nullptr,
    1,
    nullptr,
    0
  );
}

void loop() {
  printTimingOncePerSecond();
  delay(20);
}
